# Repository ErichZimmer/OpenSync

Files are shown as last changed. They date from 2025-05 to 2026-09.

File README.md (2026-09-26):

# OpenSync
An open source synchronizer for the velocimetry of fluids using a Raspberry Pi microcontroller.

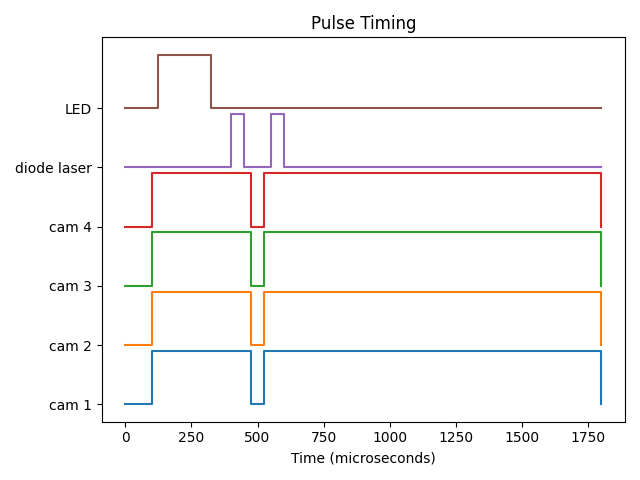
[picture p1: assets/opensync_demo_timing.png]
Example Timing Graph for Diode Laser


## Purpose
OpenSync is a simple and low-cost synchronizer based on microcontroller technology. Due to the intrinsic nature of microcontrollers compared to more advanced devices (e.g., field programmable gate arrays), sub-cycle accuracy and come complex features that are typical of commercial propietary devices are not implemented. However, OpenSync remains sufficiently flexible and provides enough support for most users' needs when performing a PIV experiment. This is because OpenSync is a digital delay/pulse generator capable of having each output channel individually programmed. In adition to an all-microcontroller platform and a custom PCB, OpenSync devices provides a low-cost means to deterministic controll of laboratory equipment.

## Basic Specs
 - **System Frequency**: 250 MHz (4 ns resolution)
 - **Output Channels**: 8
 - **Input Channels**: 2
 - **I/O Channel Voltage**: 3.3V or 5V @ high impedance

For a more detailed specification, please read the [datasheet](documents/datasheet/opensync_datasheet_markdown.md).

## Documentation
Complete instructions to construct and use OpenSync are provided in [imaginary link to notebook-based rtd website]. User's interested in the development process of OpenSync are kindly refered to the [SDLC documentation](documents/SDLC/README.md). There is a lot of information on the development process including some quirks from the pico microcontroller platform.

## Quick Start

### Compilation
OpenSync uses the [RP2350](https://www.raspberrypi.com/products/rp2350/) microcontroller and [Pico SDK](https://www.raspberrypi.com/documentation/microcontrollers/c_sdk.html) as the basis for developing devices that require precise timing with great flexibility. However, there currently isn't an official IDE like the arduino IDE for this microcontroller. Instead, [Microsoft Visual Code](https://code.visualstudio.com/) with the [Pico SDK plugin](https://marketplace.visualstudio.com/items?itemName=raspberry-pi.raspberry-pi-pico) will be used as the IDE to compile the software. Compilation is extremely simple in this context as the IDE and CMake files take care of all the compilation steps. Simply open the root directory of the OpenSync source code with Microsoft Visual Code and click on `>>Compile<<` on the bottom right corner. This will generate the .uf2 file necessary for flashing firmware to the microcontroller.

### Flashing
Flashing firmware to OpenSync is extremely simple. Make sure OpenSync is disconnected from the computer. With the top cover off, press down on the white button on the Pico 2 development board and plug in OpenSync to a computer containing the .uf2 file generated during the compilation process. OpenSync will register itself as a storage device on most computers. Open the folder for OpenSync and drag the .uf2 file into the root directory. OpenSync should then disconnect and reconnect with the computer. During the first bootup, all status LEDs will turn on which indicated that the firmware has been successfully flashed.

### Self Test
Import the Python library `opensync` and type in the following command:
```python
import opensync

# Find all open ports
ports = opensync.device_comm_search()
print(ports)

# Open serial connection with the first opensync device
with opensync.device_comm_managed(ports[0], fast=True) as device:
    # Print manufacturer, model, serial number, and firmware version
    print(opensync.device_system_version(device))

    # Perform a system operation test (raises if something goes wrong)
    opensync.device_system_test(sync_device)

```
If successfull, no errors or warnings should be produced. Please note that all commands to and from opensync are terminated with CRLF. Additionally, all used output terminals should be validated on an osciliscope for peace-of-mind, allthough this is not strictly necessary.

## Acknowledgments
I would like to acknowledge Dr. Ivan Nepomnyashchikh and Professor Alex Liberzon for spearheading development of open source, open hardware equipment for the OpenPIV project (see the original [thread](https://groups.google.com/g/openpiv-users/c/xi7qt28IGEE) that started this project). Additionally, certain inspirations of the OpenSync project are from relatively low-cost hardware produced by [Optolution](https://optolution.com/en/) and [MicroVec Pte Ltd](https://piv.com.sg/). 

## TODO
- [x] Add timing plot utilities
- [x] Add device containerization for customization
- [x] Add the ability to change channel names
- [x] Add the ability to disable output channels (necessary?)
- [x] Add three internal timers that can be mapped to pulse sequences
- [x] Add the ability to count and skip external triggers (usefull for phase-locked stuff like rotor blades)
- [x] Add second external trigger and output port masking
- [x] Update firmware and software to reflect new design
- [ ] Get the damn production PCB produced (keep pushing it off to a later date, umpf)
- [ ] Validate PCB against an osciliscope
- [ ] Add video examples on YouTube

## References
 1. Radim Hošák, & Miroslav Ježek. (2018). Arbitrary digital pulse sequence generator with delay-loop timing. Review of Scientific Instruments, 89(4). https://doi.org/10.1063/1.5019685
 2. Scallon, A. (2017, June 18). Arduino TTL Pulse Generator and Controller. Optogenetics and Neural Engineering Core. https://optogeneticsandneuralengineeringcore.gitlab.io/ONECoreSite/projects/Arduino%20TTL%20Pulse%20Generator%20and%20Controller/
 3. Starkey, P. T., Turnbaugh, C., Miller, P., LeBlanc, K.-J., & Meyer, D. H. (2024). Experimental timing and control using microcontrollers. Review of Scientific Instruments, 95(10). https://doi.org/10.1063/5.0225550
 4. Stasicki, B. and Ehrenfried, K. and Dieterle, L. and Ludwikowski, K. and Raffel, M.  (2001) Advanced syncronization techniques for complex flow field investigations by means of PIV .    4th Intern. Symposium on Particle Image Velocimetry, Göttingen, Germany, September 17-19, 2001.  
    
## Licensing

| Licenses | OSHWA UID |
| --- | --- |
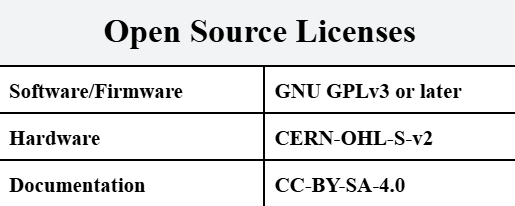
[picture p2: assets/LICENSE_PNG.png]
osls
|  | N/A |

- Software: All firmware and software components are covered by the GNU GPLv3 license.
- Hardware: All hardware is covered by the CERN-OHL-S-v2 license.

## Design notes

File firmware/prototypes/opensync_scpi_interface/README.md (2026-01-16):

# OpenSync SCPI Interface Prototype

This was a quick SCPI interface test using [scpi-parser](https://github.com/j123b567/scpi-parser) by Jan Breuer. This repository is basically a copy of his parser guide from [here](https://www.jaybee.cz/scpi-parser/basic/instrument/) and [USBTMC Pico](https://github.com/jancumps/pico_scpi_usbtmc_labtool) SCPI tool for LabView.

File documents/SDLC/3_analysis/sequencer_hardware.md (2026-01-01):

# On the design and implementation of a Synchronizer Timing Hardware

## Version History
| Date | Version | Change | 
| --- | --- | --- |
| 10/24/2025 | 0.1.0 | Intitial publishment. |
| 12/31/2026 | 0.2.0 | Updated document. |

## Key Words
- GPIO - General Purpose Input/Output
- IC - Internal Circuit
- PCB - Printed Circuit Board

## 1. Introduction
The design and construction of the OpenSync synchronizer will consist of two parts: the PCB and its associated enclosure. The PCB contains all electronics and should ideally require minimal soldering after reception from a PCB assembly vendor. To protect the PCB from the external environment, an enclosure that can be constructed using additive manufacturing technology (e.g., 3D-printing) will also be designed. The combination of easily obtainable PCBs and enclosures is of significant importance as highlighted below.

## 2.1 Enclosure
Electronics, especially specialized laboratory equipment, are often used throughout different environments that require some degree of isolation from. For instance, dusty environments can cause shorts in exposed circuit boards. Enclosures for PCBs are often the most suitable form of isolation for PCBs due to their simplicity. In the case for a multi-channel digital delay/pulse generator, a simple enclosure to protect the housed circuitry is often enough in most scenarios. This allows for the design of an enclosure to fascilitate easy of use while providing protection for internal circuity to be mostly trivial.

Since the main PCB of the synchronizer device is a half Eurocard, standardized enclosures already exist in the European market. The materials of these encolsures range from plastic to aluminium. However, modifying these pre-existing encolusres to the needs of this project may be quite cumbersome. As such, a different approach has been taken through the use of additive manufacturing technology. Additive manufacturing has become significantly more acessibly during recent years. For instance, a vat photopolymerization printer can be aquired from several different Chinese manufactures with manufacturing volumes exceeding 200 mm x 120 mm x 200 mm for less than $300 USD. Furthermore, the precision of these conumer-grade additive manufacturing systems has increased to beyond 20 microns. This is particularly important for the manufacturing of precision nozzles used in helium-filled soap bubble generators.

The use of additive manufacturing to construct enclosures is of particular interest throughout this project due to the ability to manufacturer encolusres with most, if not all, mounts and holes pre-fabricated. This low barrier to fabrication is of particular importance since many potential users of OpenSync synchronizers would be undergraduate students who may lack expertise in manufacturing custom equipment. Moreso, it would be particularly cumbersome to machine 15 holes for SMB jacks and a further 3 for status LEDs, especially for metallic enclosures. To help minimize possible difficulties during hte manufacturing processes, all designs should careffully bear in mind the current liomitations of filamet and resin-based additive manufacturing technologies.

## 2.2 Input/Output Channels
OpenSync is a 16 channel synchronizer that includes a further 3 input channels to help fascilitate advanced fluid flow measurements. The input and output channels are arranged in three rows of five with a gap of 1 cm between the centers of each jack for the input and output channels respectively. Due to the tight proximity of which the input and output jacks are placed, the jacks utilized on this device would be of the type SMB instead of the more common BNC connectors/jacks. SMB connectors do not require a twisting action to create an attachment and instead operate on the basis of friction. This may help reduce the amount of fideling required to connect equipment to the synchronizer. All input and output ports use 50 Ohm resistance at 5V since most laboratory equipment use this level of impedance. 

## 2.3 Microcontroller Circuitry
The main selling point of OpenSync is its low cost of aquisition. This is particularly attributed to the electronics used on the PCB which are based around microcontroller technology. The main sequence processor is the RP2350B (QFN-80 package) microcontroller which runs on 3.3V with rather basic fault tolerance for 5V overvoltages. To minimize the risk of damage to the general purpose input/output (GPIO) pins, a logic level translator is used to profive a buffer between 5V outputs and the 3.3V operatuing voltage of the microcontroller. It is of particular importance that the internal circuit (IC) used for translating 3.3V logic to 5V logic allows for high throughput and low rise/fall times. For this particular case, the SN74LVC8T245 transciever provides a reliable form of logic translation with rise and fall times on the order of nanoseconds on the single digit scale. To provide 5V tolerance to the input channels of the synchronizer, Schmidt triggers are a simple and fast IC that can natively provide 5V tolerance for 3.3V microcontroller oeprating voltages. Beyond ICs that provide 5V tolerances, all other ICs such as the crystal oscilator, 5V to 3V power conversion, and more are nearly identical to that of the RP2350 hardware minimal design example provided by the Raspberry Pi Foudnation.

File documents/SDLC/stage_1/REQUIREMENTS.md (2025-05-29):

# On Requirements for Synchronization of Laboratory Equipment

## Introduction
Synchronization devices play a crucial role in various laboratory experiments, particularly in fields that require precise timing and coordination among multiple components. These devices allow for laboratory equipment to work together in order to accomplish a common task. In the case for fluid dynamics, accurate and precise timing of equipment is particularly important since minor timing discrepancies can lead to non-insignificant errors in data collection and analysis. This has lead to commercial entities providing synchronizing devices with temporal resolutions often less than ten (10) nanoseconds along with advanced timing capabilities that are well suited for even the most complicated laboratory experiments. However, these devices come at the cost of exceedingly high cost-of-ownerships which limits them to institutions and organizations that are well funded. For example, one commercial synchronizer specialized for fluid flow measurements reportedly had a cost-of-ownership of around $9,000 USD (I. Nepomnyi, personal communication, May 18, 2025). Although some commercial entities have since targeted this barrier to entry with lower cost synchronizer models, these models compromize certain features along with cost-of-ownerships that remain a burden to institutions and organizations that are not well-funded.

The high costs of commercial synchronizing devices has lead to a high degree of inginuity in the research community. For instance, the author of this brief paper replaced expensive commercial devices with simple Arduino microcontrollers. While such solutions certainly work, they provide a slew of problems associated with custom firmware implementations. For one, these custom devices often provide limited functionality and sometimes even require reconfiguration of the whole device to change timing parameters. Furthermore, most microcontrollers are not well suited for advanced synchronizing applications due to an intrinsic feature of these devices. This creates a gap in the current research equipment market for an easy to use and advanced low-cost synchronizing device.

Microcontrollers are basically serial devices. This means that parallel execution of code requires the use of multiple cores or peripheral devices. In contrast to microcontrollers, complex programmable logic devices (CPLDs) provide a means for effecient execution of parallel code at the expensive of steeper learning curves due to the utilization of hardware design languages. CPLDs are particularly well suited for synchronization devices and have found several uses in different laboratory settings. Nonetheless, CPLDs are time consuming to program and were not investigated in detail during this brief feasibility study.

## Design Concepts
The RP2040 and RP2350 microcontrollers designed and fabricated by the Raspberry Pi foundation are somewhat unique devices in that they provide a slew of features that make them very attractive for the purposes of controlling laboratory equipment. These microcontrollers provide an efficient means of general input/output (GPIO) manipulation through programmable input/output (PIO) blocks. PIO blocks allow for fast and efficient manipulation of GPIO pins through low-level means. An important feauter of PIO blocks is their ability to run independently from the system clock. This enables for features to be implemented on microcontroller architecture that would otherwise require CPLD or similar devices. The applicability of this microcontroller for the controlling of laboratory equipment was first realized by Starkey et al. (2024) where a pseudoclock and arbitrary pulse generator was implemented with great success. The results from Starkey et al. (2024) provided sufficient evidence to investigate the offerings from the Raspberry Pi foundation for the purpose of engineering an accurate and precise synchronizing device.

The synchronization of laboratory equipment can be broken down into two steps: a synchronization clock source and a pulse generator. A synchronization clock is simply a pulse that occurs at every known timestep to initiate a pulse sequence. Synchronization clocks can be implemented as a mere square wave with a repetition frequency measured in Hertz. The pulse generator is a somewhat more complex as it requires the ability to arbitrarily execute a pulse sequence. These two components allow for the design and implementation of an effective digital pulse generator which could be used to control laboratory equipment. While Starkey et al. (2024) implemented this basic two-component design, their approach requires the utilization of at least two microcontrollers. Instead, two PIO blocks of the RP2040 or RP2350 microcontroller could be utilized for the purposes of combining these two approaches into a singular device. This has the advantage of creating a more compact device that is simpler to construct and program.

## Design Requirements
The effective control of laboratory equipment in both simple and advanced laboratory experiments is no simple feat. The commercial devices often used in these settings mostly provide features and performances that are very good and hard to obtain without in-depth research and design. While the designed synchronizer would most likely not approach performances akin to its commercial counterparts, the synchronizer should still be able to perform most laboratory experiments in a reliable and repeatable manner. This requires the identification of engineering requirements for a device of such cailiber, as seen in Table 1.

Table 1. Engineering Requirements
| Engineering Requirements | Target Value | Justification(s) | 
| --- | --- | --- |
| Power Usage (Watts) | 2.5 W | USB 2.0 can only supply so much voltage (5V @ around 500 mA). |
| Operating Fequency (MHz) | 200 MHz | A 200 MHz oeprating requency allows for a 5ns resolution in timing. |
| Internal Clocks | 4 | 4 internal clocks allows for ample room for advanced hardware synchronization. |
| Output Channels | 16 | 16 output channels provide ample room for hardware synchronization. |
| Input Channels | 2 | 2 input channels provide ample room for hardware synchronization. |
| I/O Channel Resistance (Ohms) | 50 Ohms | 50 Ohms seems to be the standard for device synchronization. |
| Clock Divider | 2 - 2^32-1 | Reduce system clock frequency to tune system to lower frequency conditions. |
| Pulse Width (us) | 1 us to 1 s | Most experiments do not require pulse lengths <1 us or >1 s. |
| Trigger Rate (KHz) | .001 KHz to 100 KHz | Most experiments do not require excessive trigger demands. |
| Internal Jitter (ns) | <10 ns | A 10 ns jitter corresponds to a 1% error or less for timing sequences of >1us resolution. |
| Trigger Jitter (ns) | <10 ns | External trigger jitter should be as low as possible to reduce phase error. 10ns jitter corresponds to <1% error for microsecond scale timing resolution. |
| Communication Protocol | USB | USB on-the-go reduces setup complexity and allows for human-readable serialized commands for ease of use. |
| Housing | 3D-printable | All housing parts should be 3D-printable to enable a wider audience to construct these devices. |

While not an exhaustive list, Table 1 serves as a basic guideline when engineering a synchronizing device. The synchronizer device should be easily constructable with minimal expertise on the user side beyond that of soldering electrical components and 3D printer maintenance and usage. Additionally, all selected electrical components should consume minimal power while being quite performant as USB power delivery is somewhat limited (e.g., ~2.5 W for USB 2.0). This requires carefull consideration of which electrical component should be utilized in order to satisfy most, if not all, of the engineering requirements. Beyond electrical considerations, the firmware of the microcontroller should provide ample means of flexibility to accomodate most use cases. In the case of fluid flow measurements, trigger rates between pulse sequences could occur at different repetition frequencies or require different external trigger configurations (e.g, see Stasicki et al., 2001). This requires for more advanced firmware design that is currently not possible on arduino-like platforms without the utilization of secondary peripheral devices.

## Device Design
The synchronization device, herein coined OpenSync, is a simple and powerfull synchronization device targeting the control of laboritory equipment commonly used in fluid flow diagnostics. OpenSync would provide 16 output channels and two input channels that could be mapped between four internal clocks. The core design of OpenSync revolves around the Raspberry Pi Pico 2 development board which utilizes the RP2350 microcontroller. Typically, the microcontroller chip would be soldered onto a custom printed circuit board (PCB) to exploit its full capabilities. However, this would necessitate the aquisition of a PCB reflow oven due to the usage of quad-flat, no leads (QFN) components which cannot be soldered by hand. This issue has been mostly elliminated by soldering the Pico 2 development board directly onto a custom PCB, thus eliminating technical difficulties that could incur from soldering QFN components. The RP2350 microcontroller has a known issue (errata 9) where a temporary latching behavior could be observed for input GPIO pins. This issue has been nearly circumvented in whole by connecting all active GPIO pins to gound pins via 8K resistors. Thus, the RP2350 microcontroller that is included in the Pico 2 development board has been selected as the best-fit architecture for this project. 

OpenSync would implement a dual architecture pulse logic that exploits the benefits associated with the PIO blocks in the RP2350 microcontroller. Each PIO block contains four state machines that run independent of the main clock. This allows for efficient manipulation of GPIO pins through programs written in a low-level language. For instance, state machines can run programs that utilize a subset of the assembly language coined PIO assembly (pioasm) that contains only seven instructions. Each instruction usually takes a single clock cycle to execute unless the state machine is stalled for one reason or another. This allows for very efficient programms to be written in pioasm that require minimal intervention with the main microcontroller processor. One issue with this configuration is that two PIO blocks cannot communicate between each other. As such, alternative means for syncronizing state machines between PIO blocks would be necessary and will be discussed later.

The dual architecture pulse logic would be implemented in two ways: one PIO block specializing in synchronizing clock sources and another PIO block focused on arbitrary pulse generation. The first PIO block, focused primarily on generating square waves for synchronizing pulse sequences, would utilize four state machines with each one synchronized within a single clock cycle of eachother. A basic pioasm program would be loaded into the memory of each state machine and executed with user-defined pulsing parameters. The pioasm program would take five inputs: external trigger pin, external trigger delay, external trigger skip, pulse repetition freqency, and pulse quantity. The control of the external trigger is defined by the first instruction in the pulse repetition frequency array which sets a flag in one of the scratch registers of the pioasm program. The amount of external triggers to skipped before triggering is controlled by the first instruction of the pulse quantity array and is stored in a second scratch register for later use. Each state machine operates its own instance of the pioasm program which enables for up to four independent clock signals to be sent simultaneously. The second PIO block focuses on an arbitrary pulse generator capable of producing up to 16 pulses (32 instructions in total) and operates in a similar fashion to the arbitrary pulse generator in Starkey et al. (2024). Similar to the pioasm program in PIO block 1, the four instances of the arbitary pulse generator pioasm program are mapped to all 16 output channels and are capable of operating asynchronously. However, mapping the state machine from PIO block 1 and PIO block 2 is not possible via firmware due to these blocks oeprating as independent systems. As such, an unconventional approach could be used to circumvent this issue.

As mentioned above, each PIO block operates mostly independent of each other. This creates a challenge when two PIO blocks are required to communicate between the two to accomplish a certain task. There are several methods to solve this challenge, however the one chosen for this project is somewhat uncommon. An interesting feature of the RP2350 microcontroller is the ability for any input GPIO pin to passivly "spy" on the state of another GPIO pin. This GPIO pin can be either configured as an output or input pin as the pin direction does not matter much in this context. This feature can be exploited by selecting four unused GPIO pins as an output pin that is mapped to one of each synchronization clocks in PIO block 1. Now, each pioasm program on PIO block 2 can passively spy on their respective GPIO trigger pin in order to determine when to execute the pulse sequence. Naturally, this method of triggering a pioasm program through stalling the state machine until a start signal is recieved would be slower on comparison to software interupts. This is because the internal trigger signal may need up to four clock cycles to be detected due to the implementation of GPIO inputs and outputs in the RP2350 architecture. This has an additional side-effect of which the internal trigger signal must be at least four clock cycles long in order to properly resolve the trigger. Since the internal trigger would theoretically would not be repeated for frequencies >1 MHz at a peak system clock frequency of 200 MHz, a trigger signal of 10 cycles was deemed sufficient for the purpose of synchronizing each channel of PIO block 2. Using this methodology, two PIO blocks can effectively communicate with each other in order to perform advanced pulse sequencing required in certain fluid flow diagnostic experiments.

## References

 1. RP2350 Datasheet, A Microcontroller by Raspberry Pi. (2023). Raspberry Pi Ltd. https://datasheets.raspberrypi.com/rp2350/rp2350-datasheet.pdf
 2. Starkey, P. T., Turnbaugh, C., Miller, P., LeBlanc, K.-J., & Meyer, D. H. (2024). Experimental timing and control using microcontrollers. Review of Scientific Instruments, 95(10). https://doi.org/10.1063/5.0225550
 3. Stasicki, B. and Ehrenfried, K. and Dieterle, L. and Ludwikowski, K. and Raffel, M.  (2001) Advanced syncronization techniques for complex flow field investigations by means of PIV .    4th Intern. Symposium on Particle Image Velocimetry, Göttingen, Germany, September 17-19, 2001.

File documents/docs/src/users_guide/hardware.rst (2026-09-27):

Hardware Guide
==============

.. note::

   **Placeholder:** the hardware construction guide has not been written yet.

This guide will cover the physical construction of an OpenSync device:

* **Electronics:** circuit boards, components, connectors, and wiring.
* **Enclosure:** housing design and mounting the electronics.
* **Machining:** enclosure openings, panel preparation, and mechanical parts.
* **Construction:** assembly sequence and checks on the completed device.

Detailed instructions, drawings, and assembly photographs will be added here.
For an assembled device, continue to the :doc:`firmware` or :doc:`software`.

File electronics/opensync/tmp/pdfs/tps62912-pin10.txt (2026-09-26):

                                                                                                                             TPS62912, TPS62913
                                                                                              SLVSFP4B – AUGUST 2020 – REVISED MARCH 2021

     TPS6291x 3-V to 17-V, 2-A/3-A Low Noise and Low Ripple Buck Converter with
                     Integrated Ferrite Bead Filter Compensation

1 Features                                                             3 Description
•   Low output 1/f noise < 20 µVRMS                                    The TPS6291x devices are a family of high-efficiency,
    (100 Hz to 100 kHz)                                                low noise and low ripple current mode synchronous
•   Low output voltage ripple < 10 µVRMS after ferrite                 buck converters. The devices are ideal for noise
    bead                                                               sensitive applications that would normally use an LDO
•   High PSRR of > 65 dB (up to 100 kHz)                               for post regulation such as high-speed ADCs, clock
•   2.2-MHz or 1-MHz fixed frequency peak current                      and jitter cleaner, serializer, de-serializer, and radar
    mode control                                                       applications.
•   Synchronizable with external clock (optional)                      The devices operate at a fixed switching frequency of
•   Integrated loop compensation supports ferrite                      2.2 MHz or 1 MHz, and can be synchronized to an
    bead for second stage L-C filter with 30-dB                        external clock.
    attenuation (optional)                                             To further reduce the output voltage ripple, the device
•   Spread spectrum modulation (optional)                              integrates loop compensation to operate with an
•   3.0-V to 17-V input voltage range                                  optional second-stage ferrite bead L-C filter. This
•   0.8-V to 5.5-V output voltage range                                allows an output voltage ripple below 10 µVRMS.
•   57-mΩ/20-mΩ RDSon                                                  Low-frequency noise levels, similar to a low-noise
•   Output voltage accuracy of ±1%                                     LDO, are achieved by filtering the internal voltage
•   Precise enable input allows                                        reference with a capacitor connected to the NR/SS
    – User-defined undervoltage lockout                                pin.
    – Exact sequencing                                                 The optional spread spectrum modulation scheme
•   Adjustable soft start                                              spreads the DC/DC switching frequency over a wider
•   Power-good output                                                  span, which lowers the mixing spurs.
•   Output discharge (optional)
                                                                                               Device Information
•   –40°C to 150°C junction temperature range
                                                                         DEVICE         OUTPUT                         (1)
•   2.0-mm × 2.0-mm QFN with 0.5-mm pitch                                                              PACKAGE                  BODY SIZE (NOM)
                                                                          NAME         CURRENT
•   Create a custom design using the TPS6291x with                     TPS62912             2A
    the WEBENCH® Power Designer                                                                         QFN (10)                 2.0 mm × 2.0 mm
                                                                       TPS62913             3A
2 Applications                                                         (1)    For all available packages, see the orderable addendum at
•   Telecom infrastructure                                                    the end of the data sheet.
•   Test and measurement
•   Aerospace and defense (radar/avionics)
•   Medical
                                                                                                                                      Ferrite
                                                                                                       2.2µH                          Bead
                                                             Vin                     VIN         SW                                                      Vo
                                                             12V                                                                                      3.3V/3A
                                                              2x10µF                 EN/SYNC     VO
                                                                                                                             3x22µF
                                                                                     S-CONF      FB
                                                                                                                                            15.4k
                                                                             2.2nF                                                                  2x22µF
                                                                                     PSNS      NR/SS
                                                                                                               470nF                        4.87k
                                                                                     PGND        PG

                                                                                              Typical Application
            Output Noise Versus Frequency

     An IMPORTANT NOTICE at the end of this data sheet addresses availability, warranty, changes, use in safety-critical applications,
     intellectual property matters and other important disclaimers. PRODUCTION DATA.

TPS62912, TPS62913
SLVSFP4B – AUGUST 2020 – REVISED MARCH 2021                                                                                                                      www.ti.com

                                                                        Table of Contents
1 Features............................................................................1     7.4 Device Functional Modes..........................................21
2 Applications..................................................................... 1     8 Application and Implementation.................................. 22
3 Description.......................................................................1       8.1 Application Information............................................. 22
4 Revision History.............................................................. 2          8.2 Typical Applications.................................................. 22
5 Pin Configuration and Functions...................................3                     9 Power Supply Recommendations................................30
6 Specifications.................................................................. 4      10 Layout...........................................................................30
  6.1 Absolute Maximum Ratings ....................................... 4                    10.1 Layout Guidelines................................................... 30
  6.2 ESD Ratings .............................................................. 4          10.2 Layout Example...................................................... 31
  6.3 Recommended Operating Conditions ........................4                          11 Device and Documentation Support..........................33
  6.4 Thermal Information ...................................................5              11.1 Device Support........................................................33
  6.5 Electrical Characteristics ............................................5              11.2 Receiving Notification of Documentation Updates.. 33
  6.6 Typical Characteristics................................................ 7             11.3 Support Resources................................................. 33
7 Detailed Description......................................................17              11.5 Electrostatic Discharge Caution.............................. 33
  7.1 Overview................................................................... 17        11.6 Glossary.................................................................. 33
  7.2 Functional Block Diagram......................................... 17                12 Mechanical, Packaging, and Orderable
  7.3 Feature Description...................................................18              Information.................................................................... 34

4 Revision History
Changes from Revision A (September 2020) to Revision B (March 2021)                                                        Page
• Changed device status from Advance Information to Production Data ............................................................. 1

2       Submit Document Feedback                                                                                           Copyright © 2021 Texas Instruments Incorporated

                                                              Product Folder Links: TPS62912 TPS62913

                                                                                                                                      TPS62912, TPS62913
www.ti.com                                                                                                      SLVSFP4B – AUGUST 2020 – REVISED MARCH 2021

5 Pin Configuration and Functions
                                                           PGND 4                            3 VO
                                                               PG 5                          2 SW
                                                              VIN 6                          1 EN/SYNC

                                                                      7     8       9 10

                                                                            NR/SS
                                                                                    FB
                                                                                         S-CONF
                                                                     PSNS
                                          Figure 5-1. 10-Pin QFN RPU Package (Top View)

                                                              Table 5-1. Pin Functions
           PIN
                           I/O                                                                    DESCRIPTION
    NO.     NAME
                                 Enable/Disable pin including threshold-comparator. Connect to logic low to disable the device. Pull high to enable the device.
     1      EN/SYNC         I    This pin has an internal pulldown resistor of typically 500 kΩ when the device is disabled. Apply a clock to this pin to
                                 synchronize the device.
     2      SW             I/O   Switch pin of the power stage
     3      VO              I    Output voltage sense pin. This pin needs to be connected directly after the first inductor.
     4      PGND                 Power ground connection
                                 Open-drain power-good output. This pin is pulled to GND when VOUT is below the power-good threshold. It requires a pullup
     5      PG              O
                                 resistor to output a logic high. It can be left open or tied to GND if not used.
     6      VIN             I    Power supply input voltage pin
     7      PSNS            I    Power sense ground. Connect directly to the ground plane.
     8      NR/SS           O    A capacitor connected to this pin sets the soft-start time and low frequency noise level of the device.
     9      FB              I    Feedback pin of the device
     10     S-CONF          O    Smart Configuration pin. This pin configures the operation modes of the device. See Table 7-1.

Copyright © 2021 Texas Instruments Incorporated                                                                                Submit Document Feedback           3
                                                      Product Folder Links: TPS62912 TPS62913

TPS62912, TPS62913
SLVSFP4B – AUGUST 2020 – REVISED MARCH 2021                                                                                               www.ti.com

6 Specifications
6.1 Absolute Maximum Ratings
over operating junction temperature range (unless otherwise noted)(1)
                                                                                                        MIN                MAX            UNIT
                         VIN, EN/SYNC, PG, S-CONF                                                      – 0.3                  18           V
                         SW (DC)                                                                       – 0.3          VIN + 0.3            V
    Voltage(2)           SW (AC, less than 10ns)(3)                                                    – 2.5                  21           V
                         VO, FB, NR/SS                                                                 – 0.3                   6           V
                         PSNS                                                                          – 0.3                  0.3          V
    Sink Current         PG                                                                                                   10          mA
    TJ                   Junction temperature                                                           –40                150             °C
    Tstg                 Storage temperature                                                            –65                150             °C

(1)          Stresses beyond those listed under Absolute Maximum Rating may cause permanent damage to the device. These are stress
             ratings only, which do not imply functional operation of the device at these or any other conditions beyond those indicated
             under Recommended Operating Condition. Exposure to absolute-maximum-rated conditions for extended periods may affect device
             reliability.
(2)          All voltage values are with respect to the network ground terminal
(3)          While switching

6.2 ESD Ratings
                                                                                                                      VALUE                UNIT
                                                       Human body model (HBM), per ANSI/ESDA/JEDEC JS-001,
                                                                                                                      ±2000
                                                       all pins(1)
    V(ESD)             Electrostatic discharge                                                                                              V
                                                       Charged device model (CDM), per JEDEC specification
                                                                                                                       ±500
                                                       JESD22-C101, all pins(2)

(1)          JEDEC document JEP155 states that 500-V HBM allows safe manufacturing with a standard ESD control process.
(2)          JEDEC document JEP157 states that 250-V CDM allows safe manufacturing with a standard ESD control process.

6.3 Recommended Operating Conditions
over operating junction temperature range (unless otherwise noted)
                                                                                                     MIN          NOM           MAX         UNIT
    VIN             Input voltage                                                                     3.0                            17         V
    VOUT            Output voltage                                                                    0.8                           5.5         V
    CIN             Effective input capacitance                                                         5            10                        µF
    L1              Effective output inductance                                                     -30%       2.2 / 4.7            20%        µH
    COUT            Effective output capacitance                                                       40            47              80        µF
    Lf              Effective filter inductance                                                         0            10              50        nH
    Cf              Effective filter capacitance                                                       20            40             160        µF
    COUT + Cf       Effective total output capacitance, including first and second L-C filter          40                           200        µF
    IOUT            Output current for TPS62913                                                         0                             3         A
    IOUT            Output current for TPS62912                                                         0                             2         A
    TJ (1)          Junction temperature                                                             –40                            150        °C

(1)          Operating lifetime is derated at junction temperatures above 125°C.

4            Submit Document Feedback                                                                  Copyright © 2021 Texas Instruments Incorporated

                                                         Product Folder Links: TPS62912 TPS62913

                                                                                                                                TPS62912, TPS62913
www.ti.com                                                                                           SLVSFP4B – AUGUST 2020 – REVISED MARCH 2021

6.4 Thermal Information
                                                                                                     TPS6291x
                           THERMAL METRIC(1)                                                     RPU 10-pin QFN                              UNIT
                                                                                 JEDEC 51-7 PCB              TPS6291xEVM-077
 RθJA             Junction-to-ambient thermal resistance                                87.7                          56.6                   °C/W
 RθJC(top)        Junction-to-case (top) thermal resistance                             61.9                          n/a (2)                °C/W
 RθJB             Junction-to-board thermal resistance                                  22.2                          n/a (2)                °C/W
 ΨJT              Junction-to-top characterization parameter                             1.9                           1.3                   °C/W
 YJB              Junction-to-board characterization parameter                          22.2                          22.7                   °C/W

(1)       For more information about traditional and new thermal metrics, see the Semiconductor and IC Package Thermal Metrics application
          report.
(2)       Not applicable to an EVM

6.5 Electrical Characteristics
Over recommended input voltage range, TJ= -40℃ to 150℃. Typical values are at Vin=12V andTJ=25℃ (unless otherwise
noted)
                       PARAMETER                                          TEST CONDITIONS                     MIN          TYP       MAX      UNIT
 SUPPLY
                                                            EN = High, no load, device switching, fsw
 IQ            Quiescent current                                                                                                 5            mA
                                                            = 1 MHz
 ISD           Shutdown current                             EN = GND, TJ = -40°C to 125°C                                    0.3       70      µA
 VUVLO         Undervoltage lockout                         VIN rising, TJ = -40°C to 125°C                   2.85         2.92        3.0     V
 VUVLO         Undervoltage lockout                         VIN rising                                                                3.04     V
 VHYS          Undervoltage lockout hysteresis                                                                               200              mV
               Thermal shutdown threshold                   TJ rising                                                        170               °C
 TJSD
               Thermal shutdown hysteresis                  TJ falling                                                          20             °C
 CONTROL and INTERFACE
               High-level input-threshold voltage at EN/
 VH_EN                                                                                                        0.97         1.01       1.04     V
               SYNC
               Low-level input-threshold voltage at EN/
 VL_EN                                                                                                        0.87           0.9      0.93     V
               SYNC
               High-level input-threshold clock signal on
 VH_SYNC                                                    EN/SYNC = clock                                     1.1                            V
               EN/SYNC
               Low-level input-threshold clock signal on
 VL_SYNC                                                    EN/SYNC = clock                                                            0.4     V
               EN/SYNC
                                                            EN/SYNC = GND or VIN, –40℃ ≤ TJ ≤
 IEN,LKG       Input leakage current into EN/SYNC                                                                                5    160      nA
                                                            125℃
 RPD           Pulldown resistor on EN/SYNC                 EN/SYNC = Low                                       330          500               kΩ
                                                            Time from EN/SYNC high to device starts
 tdelay        Enable delay time                                                                                                 1             ms
                                                            switching, RS-CONF = 80.6 kΩ
 INR/SS        NR/SS source current                                                                           67.5              75    82.5     µA
                                                            RS-CONF tolerance for all settings
 RS-CONF       S-CONF resistor step range accuracy                                                            –4%                     +4%
                                                            according to S-CONF Table
 VPG           Power good threshold                         VFB rising, referenced to VFB nominal             93%          95%        98%
 VPG           Power good threshold                         VFB falling, referenced to VFB nominal            88%          90%        93%
 VPG,OL        Low-level output voltage at PG pin           ISINK = 1 mA                                                               0.4     V
 IPG,LKG       Input leakage current into PG pin            VPG = 5 V; –40℃ ≤ TJ ≤ 125℃                                          5    500      nA
 tPG,DLY       Power good delay time                        VFB falling                                                          8             µs
 OUTPUT

Copyright © 2021 Texas Instruments Incorporated                                                                   Submit Document Feedback           5
                                                    Product Folder Links: TPS62912 TPS62913

TPS62912, TPS62913
SLVSFP4B – AUGUST 2020 – REVISED MARCH 2021                                                                                       www.ti.com

Over recommended input voltage range, TJ= -40℃ to 150℃. Typical values are at Vin=12V andTJ=25℃ (unless otherwise
noted)
                          PARAMETER                               TEST CONDITIONS                      MIN        TYP        MAX      UNIT
    ton          Minimum on-time                      VIN ≥ 5 V, Iout = 1 A                                         35          70      ns
    toff         Minimum off-time                     VIN ≥ 5 V, Iout = 1 A                                         50          60      ns
    VFB          Feedback regulation accuracy         –40℃ ≤TJ ≤ 150℃                                0.792         0.8      0.812       V
    VFB          Feedback regulation accuracy         –40℃ ≤ TJ ≤ 125℃                               0.792         0.8      0.808       V
    IFB,LKG      Input leakage current into FB        VFB = 0.8 V, –40℃ ≤ TJ ≤ 125℃                                  1          70     nA
    IVO,LKG      Input leakage current into VO        VVO = 1.2 V, –40℃ ≤ TJ ≤ 125℃                               0.01          30     µA
                                                      VIN = 12 V, 1.2 VOUT, 1 A, CNR/SS = 470
    PSRR         Power supply rejection ratio         nF, fsw = 1 MHz, CFF = open, L1 = 2.2 µH,                     65                 dB
                                                      COUT = 3 × 22 µF, f ≤ 100 kHz
                                                      VIN = 5 V, 1.2 VOUT, 1 A, CNR/SS = 470 nF,
    PSRR         Power supply rejection ratio         fsw = 2.2 MHz, CFF = open, L1 = 2.2 µH,                       70                 dB
                                                      COUT = 3 × 22 µF, f ≤ 100 kHz
                                                      VIN = 12 V, BW = 100 Hz to 100 kHz, CNR/
                                                      SS = 470 nF, fSW = 1 MHz, VOUT = 1.2 V,
    VNRMS        Output voltage RMS noise                                                                         24.4               µVRMS
                                                      CFF = open, L1 = 2.2 µH, COUT = 3 × 22
                                                      µF
                                                      VIN = 5 V, BW = 100 Hz to 100 kHz, CNR/
                                                      SS = 470 nF, fSW = 2.2 Hz, VOUT = 1.2 V,
    VNRMS        Output voltage RMS noise                                                                         13.5               µVRMS
                                                      CFF = open, L1 = 2.2 µH, COUT = 3 × 22
                                                      µF
                                                      VIN = 12 V, fSW = 1 MHz, VOUT = 1.2 V, L1
    Vopp         Output ripple voltage at fSW         = 4.7 µH, COUT = 3 × 22 µF, Lf = 10 nH,                        9               µVRMS
                                                      Cf = 2 × 22 µF
                                                      VIN = 5 V, fSW = 2.2 MHz, VOUT = 1.2 V, L1
    Vopp         Output ripple voltage at fSW         = 2.2 µH, COUT = 3 × 22 µF, Lf = 10 nH,                    < 2.2               µVRMS
                                                      Cf = 2 × 22 μF
                                                      EN/SYNC = GND, VOUT = 1.2 V, VIN ≥ 5
    RDIS         Output discharge resistance                                                                          7                 Ω
                                                      V. See Typical Char for plot.
                                                      EN/SYNC = GND, VOUT = 5 V, VIN ≥ 5 V.
    RDIS         Output discharge resistance                                                                        32                  Ω
                                                      See Typical Char for plot.
    fSW          Switching frequency                  2.2-MHz setting                                 1.98         2.2        2.42    MHz
    fSW          Synchronization range                2.2-MHz setting                                   1.9        2.2        2.42    MHz
    fSW          Switching frequency                  1-MHz setting                                     0.9          1        1.18    MHz
    fSW          Synchronization range                1-MHz setting                                   0.86           1         1.2    MHz
    DSYNC        Synchronization duty cycle                                                           45%                     55%
                                                      Phase delay from EN/SYNC rising edge
    tsync_elay   Synchronization phase delay                                                                        90                  ns
                                                      to SW rising edge
    ISWpeak      Peak switch current limit            TPS62912                                          2.9        3.5         4.0      A
    ISWpeak      Peak switch current limit            TPS62913                                          3.7        4.3         5.1      A
    ISWvalley    Valley switch current limit          TPS62912                                                     3.4                  A
    ISWvalley    Valley switch current limit          TPS62913                                                     4.2                  A
    Inegvalley Negative valley current limit                                                                     –1.39      –0.96       A
                 High-side FET on-resistance          VIN ≥ 5 V                                                     57          95     mΩ
    RDS(ON)
                 Low-side FET on-resistance           VIN ≥ 5 V                                                     20          39     mΩ

6          Submit Document Feedback                                                                Copyright © 2021 Texas Instruments Incorporated

                                                 Product Folder Links: TPS62912 TPS62913

                                                                                                                  TPS62912, TPS62913
www.ti.com                                                                                   SLVSFP4B – AUGUST 2020 – REVISED MARCH 2021

6.6 Typical Characteristics
VIN = 12 V, VOUT = 1.2 V, TA = 25°C, BOM = Table 8-1, (unless otherwise noted)

                                                                                                BW = 10 kHz
   12 V to 1.2 V, 1 A       2.2 μH, 1 MHz         First L-C Only
                                                                        12 V to 1.2 V, 1 A     2.2 μH, 1 MHz       First L-C Only
           Figure 6-1. VOUT Ripple After the First L-C Filter
                                                                             Figure 6-2. VOUT Ripple FFT After the First L-C Filter

                                                                                               BW = 10 kHz
   12 V to 1.2 V, 1 A      2.2 μH, 1 MHz      First and second L-C
                                                                        12 V to 1.2 V, 1 A     2.2 μH, 1 MHz   First and second L-C
         Figure 6-3. VOUT Ripple After the Second L-C Filter
                                                                           Figure 6-4. VOUT Ripple FFT After the Second L-C Filter

   12 V to 1.2 V, 1 A       2.2 μH, 1 MHz         First L-C Only        12 V to 1.2 V, 1 A    2.2 μH, 1 MHz    First and second L-C

              With Random Spread Spectrum Enabled                                With Random Spread Spectrum Enabled

           Figure 6-5. VOUT Ripple After the First L-C Filter                Figure 6-6. VOUT Ripple After the Second L-C Filter

Copyright © 2021 Texas Instruments Incorporated                                                           Submit Document Feedback         7
                                                   Product Folder Links: TPS62912 TPS62913

TPS62912, TPS62913
SLVSFP4B – AUGUST 2020 – REVISED MARCH 2021                                                                                    www.ti.com

6.6 Typical Characteristics (continued)

    12 V to 1.8 V, 1 A    2.2 μH, 1 MHz        First L-C Only
                                                                                             BW = 10 kHz

                                                                      12 V to 1.8 V, 1 A    2.2 μH, 1 MHz          First L-C Only
           Figure 6-7. VOUT Ripple After the First L-C Filter
                                                                           Figure 6-8. VOUT Ripple FFT After the First L-C Filter

    12 V to 1.8 V, 1 A   2.2 μH, 1 MHz     First and second L-C
                                                                                            BW = 10 kHz

                                                                      12 V to 1.8 V, 1 A   2.2 μH, 1 MHz      First and second L-C
         Figure 6-9. VOUT Ripple After the Second L-C Filter
                                                                         Figure 6-10. VOUT Ripple FFT After the Second L-C Filter

    12 V to 3.3 V, 1 A   2.2 μH, 2.2 MHz       First L-C Only
                                                                                             BW = 10 kHz

                                                                      12 V to 3.3 V, 1 A   2.2 μH, 2.2 MHz         First L-C Only
          Figure 6-11. VOUT Ripple After the First L-C Filter
                                                                          Figure 6-12. VOUT Ripple FFT After the First L-C Filter

8      Submit Document Feedback                                                                 Copyright © 2021 Texas Instruments Incorporated

                                                 Product Folder Links: TPS62912 TPS62913

                                                                                                                  TPS62912, TPS62913
www.ti.com                                                                                   SLVSFP4B – AUGUST 2020 – REVISED MARCH 2021

6.6 Typical Characteristics (continued)

   12 V to 3.3 V, 1 A     2.2 μH, 2.2 MHz     First and second L-C
                                                                                               BW = 10 kHz

                                                                        12 V to 3.3 V, 1 A    2.2 μH, 2.2 MHz   First and second L-C
         Figure 6-13. VOUT Ripple After the Second L-C Filter
                                                                           Figure 6-14. VOUT Ripple FFT After the Second L-C Filter

    5 V to 1.2 V, 1 A      2.2 μH, 2.2 MHz        First L-C Only
                                                                                                BW = 10 kHz

                                                                         5 V to 1.2 V, 1 A    2.2 μH, 2.2 MHz       First L-C Only
          Figure 6-15. VOUT Ripple After the First L-C Filter
                                                                            Figure 6-16. VOUT Ripple FFT After the First L-C Filter

    5 V to 1.2 V, 1 A     2.2 μH, 2.2 MHz     First and second L-C
                                                                                               BW = 10 kHz

                                                                         5 V to 1.2 V, 1 A    2.2 μH, 2.2 MHz   First and second L-C
         Figure 6-17. VOUT Ripple after the Second L-C Filter
                                                                           Figure 6-18. VOUT Ripple FFT After the Second L-C Filter

Copyright © 2021 Texas Instruments Incorporated                                                           Submit Document Feedback         9
                                                   Product Folder Links: TPS62912 TPS62913

TPS62912, TPS62913
SLVSFP4B – AUGUST 2020 – REVISED MARCH 2021                                                                                   www.ti.com

6.6 Typical Characteristics (continued)

     5 V to 1.8 V, 1 A    2.2 μH, 2.2 MHz       First L-C Only
                                                                                             BW = 10 kHz

                                                                       5 V to 1.8 V, 1 A   2.2 μH, 2.2 MHz        First L-C Only
           Figure 6-19. VOUT Ripple After the First L-C Filter
                                                                          Figure 6-20. VOUT Ripple FFT After the First L-C Filter

     5 V to 1.8 V, 1 A   2.2 μH, 2.2 MHz    First and second L-C
                                                                                            BW = 10 kHz

                                                                       5 V to 1.8 V, 1 A   2.2 μH, 2.2 MHz   First and second L-C
         Figure 6-21. VOUT Ripple After the Second L-C Filter
                                                                         Figure 6-22. VOUT Ripple FFT After the Second L-C Filter

     5 V to 3.3 V, 1 A    2.2 μH, 2.2 MHz       First L-C Only
                                                                                             BW = 10 kHz

                                                                       5 V to 3.3 V, 1 A   2.2 μH, 2.2 MHz        First L-C Only
           Figure 6-23. VOUT Ripple After the First L-C Filter
                                                                          Figure 6-24. VOUT Ripple FFT After the First L-C Filter

10      Submit Document Feedback                                                               Copyright © 2021 Texas Instruments Incorporated

                                                 Product Folder Links: TPS62912 TPS62913

                                                                                                                      TPS62912, TPS62913
www.ti.com                                                                                   SLVSFP4B – AUGUST 2020 – REVISED MARCH 2021

6.6 Typical Characteristics (continued)

    5 V to 3.3 V, 1 A     2.2 μH, 2.2 MHz     First and second L-C
                                                                                                BW = 10 kHz

                                                                         5 V to 3.3 V, 1 A    2.2 μH, 2.2 MHz      First and second L-C
         Figure 6-25. VOUT Ripple After the Second L-C Filter
                                                                           Figure 6-26. VOUT Ripple FFT After the Second L-C Filter

    6 V to 1.2 V, 1 A       2.2 μH, 1 MHz          BW = 50 Hz           12 V to 1.2 V, 2 A      2.2 μH, 1 MHz           BW = 10 kHz

                S-CONF = OFF, Triangular, Random                                     S-CONF = OFF, Triangular, Random

            Figure 6-27. Spread Spectrum FFT - 50-Hz BW                         Figure 6-28. Spread Spectrum FFT - 10-kH BW

       12 V to 1.2 V         2.2 μH, 1 MHz         First L-C Only          12 V to 1.2 V       2.2 μH, 1 MHz       After ferrite bead filter

     NR/SS = Open, 100 nF, 470 nF, 2.2 μF, BW = 100 Hz to 100 kHz         NR/SS = Open, 100 nF, 470 nF, 2.2 μF, BW = 100 Hz to 100 kHz

           Figure 6-29. Output Noise Density vs Frequency                      Figure 6-30. Output Noise Density vs Frequency

Copyright © 2021 Texas Instruments Incorporated                                                                Submit Document Feedback        11
                                                   Product Folder Links: TPS62912 TPS62913

TPS62912, TPS62913
SLVSFP4B – AUGUST 2020 – REVISED MARCH 2021                                                                                              www.ti.com

6.6 Typical Characteristics (continued)

        12 V to 1.2 V         2.2 μH, 1 MHz          First L-C Only         12 V to 1.2 V        2.2 μH, 1 MHz       After ferrite bead filter

     NR/SS = 470 nF, CFF = Open, 100 nF, 1 μF, BW = 100 Hz to 100 kHz     NR/SS = 470 nF, CFF = Open, 100 nF, 1 μF, BW = 100 Hz to 100 kHz

            Figure 6-31. Output Noise Density vs Frequency                       Figure 6-32. Output Noise Density vs Frequency

        12 V to 1.8 V         2.2 μH, 1 MHz          First L-C Only          12 V to 1.8 V       2.2 μH, 1 MHz       After ferrite bead filter

       NR/SS = Open, 100 nF, 470 nF, 2.2 μF, BW = 100 Hz to 100 kHz         NR/SS = Open, 100 nF, 470 nF, 2.2 μF, BW = 100 Hz to 100 kHz

            Figure 6-33. Output Noise Density vs Frequency                       Figure 6-34. Output Noise Density vs Frequency

        12 V to 1.8 V         2.2 μH, 1 MHz          First L-C Only         12 V to 1.8 V        2.2 μH, 1 MHz      After ferrite bead filter

     NR/SS = 470 nF, CFF = Open, 100 nF, 1 μF, BW = 100 Hz to 100 kHz     NR/SS = 470 nF, CFF = Open, 100 nF, 1 μF, BW = 100 Hz to 100 kHz

            Figure 6-35. Output Noise Density vs Frequency                       Figure 6-36. Output Noise Density vs Frequency

12       Submit Document Feedback                                                                     Copyright © 2021 Texas Instruments Incorporated

                                                     Product Folder Links: TPS62912 TPS62913

                                                                                                                     TPS62912, TPS62913
www.ti.com                                                                                   SLVSFP4B – AUGUST 2020 – REVISED MARCH 2021

6.6 Typical Characteristics (continued)

                                                                           12 V to 3.3 V        2.2 μH, 2.2 MHz     After ferrite bead filter
       12 V to 3.3 V        2.2 μH, 2.2 MHz        First L-C Only
                                                                          NR/SS = Open, 100 nF, 470 nF, 2.2 μF, BW = 100 Hz to 100 kHz
     NR/SS = Open, 100 nF, 470 nF, 2.2 μF, BW = 100 Hz to 100 kHz

                                                                               Figure 6-38. Output Noise Density vs Frequency
           Figure 6-37. Output Noise Density vs Frequency

       12 V to 3.3 V        2.2 μH, 2.2 MHz        First L-C Only          12 V to 3.3 V        2.2 μH, 2.2 MHz     After ferrite bead filter

   NR/SS = 470 nF, CFF = Open, 100 nF, 1 μF, BW = 100 Hz to 100 kHz     NR/SS = 470 nF, CFF = Open, 100 nF, 1 μF, BW = 100 Hz to 100 kHz

           Figure 6-39. Output Noise Density vs Frequency                      Figure 6-40. Output Noise Density vs Frequency

       5 V to 1.2 V         2.2 μH, 2.2 MHz        First L-C Only           5 V to 1.2 V        2.2 μH, 2.2 MHz     After ferrite bead filter

     NR/SS = Open, 100 nF, 470 nF, 2.2 μF, BW = 100 Hz to 100 kHz         NR/SS = Open, 100 nF, 470 nF, 2.2 μF, BW = 100 Hz to 100 kHz

           Figure 6-41. Output Noise Density vs Frequency                      Figure 6-42. Output Noise Density vs Frequency

Copyright © 2021 Texas Instruments Incorporated                                                             Submit Document Feedback            13
                                                   Product Folder Links: TPS62912 TPS62913

TPS62912, TPS62913
SLVSFP4B – AUGUST 2020 – REVISED MARCH 2021                                                                                                 www.ti.com

6.6 Typical Characteristics (continued)

       5 V to 3.3 V           2.2 μH, 2.2 MHz       First L-C Only               5 V to 3.3 V         2.2 μH, 2.2 MHz     After ferrite bead filter

     NR/SS = Open, 100 nF, 470 nF, 2.2 μF, BW = 100 Hz to 100 kHz              NR/SS = Open, 100 nF, 470 nF, 2.2 μF, BW = 100 Hz to 100 kHz

          Figure 6-43. Output Noise Density vs Frequency                            Figure 6-44. Output Noise Density vs Frequency

     12 V to 1.2 V            2.2 μH, 1 MHz         1 A, 2 A, 3 A              12 V to 1.2 V          2.2 μH, 1 MHz           1 A, 2 A, 3 A

                      First L-C Only, No Ferrite Bead                                             After Ferrite Bead Filter

                      Figure 6-45. PSRR vs Frequency                                            Figure 6-46. PSRR vs Frequency

     12 V to 1.8 V            2.2 μH, 1 MHz         1 A, 2 A, 3 A              12 V to 1.8 V          2.2 μH, 1 MHz           1 A, 2 A, 3 A

                      First L-C Only, No Ferrite Bead                                                After Ferrite Bead

                      Figure 6-47. PSRR vs Frequency                                            Figure 6-48. PSRR vs Frequency

14     Submit Document Feedback                                                                           Copyright © 2021 Texas Instruments Incorporated

                                                        Product Folder Links: TPS62912 TPS62913

                                                                                                                  TPS62912, TPS62913
www.ti.com                                                                                    SLVSFP4B – AUGUST 2020 – REVISED MARCH 2021

6.6 Typical Characteristics (continued)

                              VIN = 5 V                                                           VIN = 5 V

      Figure 6-49. High-Side RDS(ON) vs Junction Temperature                Figure 6-50. Low-Side RDS(ON) vs Junction Temperature

                              1 MHz, 2 A                                      5 VIN to 0.8 VOUT                   1 MHz

          Figure 6-51. FB Pin Voltage Error vs Input Voltage                      Figure 6-52. Output Voltage Error vs Load

         12 VIN to 0.8 VOUT                       1 MHz                            12 VIN                         1 MHz

              Figure 6-53. Output Voltage Error vs Load                        Figure 6-54. Oscillator Frequency vs Temperature

Copyright © 2021 Texas Instruments Incorporated                                                            Submit Document Feedback     15
                                                    Product Folder Links: TPS62912 TPS62913

TPS62912, TPS62913
SLVSFP4B – AUGUST 2020 – REVISED MARCH 2021                                                                                 www.ti.com

6.6 Typical Characteristics (continued)

            12 VIN                      2.2 MHz                                         VIN: 3 V, 5 V, 12 V

        Figure 6-55. Oscillator Frequency vs Temperature                  Figure 6-56. Shutdown Current vs Temperature

                                          VIN: 12 V                        25°C

                                  Figure 6-57. Output Discharge Resistance vs Output Voltage

16    Submit Document Feedback                                                               Copyright © 2021 Texas Instruments Incorporated

                                              Product Folder Links: TPS62912 TPS62913

                                                                                                                                                        TPS62912, TPS62913
www.ti.com                                                                                                              SLVSFP4B – AUGUST 2020 – REVISED MARCH 2021

7 Detailed Description
7.1 Overview
The TPS6291x low-noise, low-ripple synchronous buck converter is a fixed frequency current mode converter.
The converter has a filtered internal reference to achieve a low-noise output similar to low-noise LDOs. The
converter achieves lower output voltage ripple by using a switching frequency of either 2.2 MHz or 1 MHz and a
larger inductance. The output voltage ripple can be further reduced by adding a small second stage L-C filter to
the output. This can be a ferrite bead or a small inductor, followed by an output capacitor. Internal compensation
maintains stability with an external filter inductor up to 50 nH. To avoid voltage drops across this second stage
filter, the device regulates the output voltage after the filter. The TPS6291x family supports an optional spread
spectrum modulation. For example, when powering ADCs, spread spectrum modulation reduces the mixing
spurs. Switching frequency, spread spectrum modulation, and output discharge are set using the S-CONF pin.
7.2 Functional Block Diagram
                                                                                                      PG                                                     VIN

                                                                                                                                      High Side
                                                                                                                                    Current Sense
                                                                          VPG     +

                                                                          VFB     t

                                                                                                                   Slope
                                                               Undervoltage
EN/SYNC                                +                                                                        Compensation             G
                                                                  lockout
                              1.0V     t                     Thermal shutdown
                 RPD

                                            Clock
                                           Detector

                                                                            MUX                            MOSFET Driver
                                                                                                         Anti Shoot Through
                             EN/SYNC                                                                   Converter Control Logic                                       SW

                 MODE                                             1MHz/2.2MHz
                                Spread Spectrum                            MODE
                                  Modulation                                                                                                   Low Side
                                                                                                                                             Current Sense

                                                                                                                                                                      PGND

                       VIN
                                                                                            Comparator

                                                                                                                                               2nd stage filter       FB
                                                                                                                                t              compensation
                                                                                                                           GM
                             Start-up readout                                                                                   +
                                                                                                                                                                      VO
                                                       S-CONF                                   VIN
 S-CONF                              ADC              Register                  MODE
                                                      Selection                                                        GM Amplifier
                                                                                                       INR/SS

                                                                                                      Softstart

                                                                                       Rf                                                                    RDIS
                                                                        VREF
                                                                        0.8V
                                                                                                                                       Output voltage
                                                                                                                    MODE                 discharge
                                                                                                                                            logic

                                                      PSNS                                    NR/SS

Copyright © 2021 Texas Instruments Incorporated                                                                                              Submit Document Feedback      17
                                                                  Product Folder Links: TPS62912 TPS62913

TPS62912, TPS62913
SLVSFP4B – AUGUST 2020 – REVISED MARCH 2021                                                                            www.ti.com

7.3 Feature Description
7.3.1 Smart Config (S-CONF)
This S-CONF pin configures the device based on the resistor value. This pin is read after EN/SYNC goes high.
The device configuration cannot be changed during operation. The S-CONF value is re-read if EN is pulled
below 200 mV or if VIN falls below UVLO. Table 7-1 shows the configuration options of the following:
•    Switching frequency
•    Spread spectrum modulation
•    Output discharge
•    Synchronization
                                  Table 7-1. S-CONF Device Configuration Modes
                    SWITCHING                                         OUTPUT
     S-CONF                             SPREAD SPECTRUM                                       SYNCHRONIZATION
                    FREQUENCY                                       DISCHARGE
      VIN             2.2 MHz                     OFF                   OFF                             No
      GND              1 MHz                      OFF                   OFF                             No
     4.87 kΩ          2.2 MHz                     OFF                   OFF                   1.9 MHz to 2.42 MHz
     6.04kΩ           2.2MHz                     Triangle               OFF                             No
     7.5 kΩ           2.2 MHz                    Random                 OFF                             No
     9.31 kΩ           1 MHz                      OFF                   OFF                    0.9 MHz to 1.2 MHz
     11.5kΩ            1MHz                      Triangle               OFF                             No
     14.3 kΩ           1 MHz                     Random                 OFF                             No
                                                                    Discharge On
     18.2 kΩ          2.2 MHz                     OFF                    ON                             No
     22.1 kΩ           1 MHz                      OFF                    ON                             No
     27.4 kΩ          2.2 MHz                     OFF                    ON                   1.9 MHz to 2.42 MHz
      34kΩ            2.2MHz                     Triangle                ON                             No
     42.2 kΩ          2.2 MHz                    Random                  ON                             No
     52.3 kΩ           1 MHz                      OFF                    ON                    0.9 MHz to 1.2 MHz
     64.9kΩ            1MHz                      Triangle                ON                             No
     80.6 kΩ           1 MHz                     Random                  ON                             No

7.3.2 Device Enable (EN/SYNC)
The device is enabled by pulling the EN/SYNC pin high, and has an accurate rising threshold voltage of typically
1.01 V. Once the device is enabled, the operation mode is set by the configuration of the S-CONF pin. This
occurs during the device start-up delay time tdelay. Once tdelay expires, the internal soft-start circuitry ramps
up the output voltage over the soft-start time set by the CNR/SS capacitor. The start-up delay time tdelay varies
depending on the selected S-CONF value. It is shortest with smaller S-CONF resistors.
The EN/SYNC pin has an active pulldown resistor RPD. This prevents an uncontrolled start-up of the device, in
case the EN/SYNC pin cannot be driven to a low level. The pulldown resistor is disconnected after start-up. With
EN set to a low level, the device enters shutdown and the pulldown resistor is activated again.
7.3.3 Device Synchronization (EN/SYNC)
The EN/SYNC pin is also used for device synchronization. Once a clock signal is applied to this pin, the device
is enabled and reads the configuration of the S-CONF pin. The external clock frequency must be within the
clock synchronization frequency range set by the S-CONF pin. When the clock signal changes from a clock to a
static high, then the device switches from external clock to internal clock. To shutdown the device when using an
external clock, EN/SYNC must go low for at least 10 µs.

18     Submit Document Feedback                                                         Copyright © 2021 Texas Instruments Incorporated

                                              Product Folder Links: TPS62912 TPS62913

                                                                                                                       TPS62912, TPS62913
www.ti.com                                                                                         SLVSFP4B – AUGUST 2020 – REVISED MARCH 2021

The clock signal can be a logic signal with a logic level as specified in the electrical table, and can be applied
directly to the EN/SYNC pin. External logic, such as an AND gate, can be used to combine separate enable and
clock inputs, as shown in Figure 7-1.

                                                                                  TPS6291x
                                                              EN
                                                                                   EN/SYNC
                                                             CLK

                                     Figure 7-1. Synchronization with Separate Enable Signal (optional)

7.3.4 Spread Spectrum Modulation
Using the S-CONF pin enables or disables spread spectrum modulation. DC/DC converters generate an output
voltage ripple at the switching frequency. When powering ADCs or an analog front end (AFE), the switching
frequency generates high frequency mixing spurs as well as a low frequency spur in the output frequency
spectrum. Using the optional second stage L-C filter reduces the ripple of the converter and spurs by up to 30
dB.
The device has integrated two different spread spectrum modulation (SSM) schemes that are selected by
the resistor connected to the S-CONF pin acording to Table 7-1. It is possible to select random or triangle
modulation to spread the switching frequency over a larger frequency range. The triangular SSM is modulated
based on the switching frequency, and results in 1.9 kHz for 1 MHz switching frequency and 4.3 kHz for
2.2 MHz switching frequency. The modulation spread is ±10% of the device switching frequency. This SSM
provides high attenuation when the receiver bandwidth is less than the modulation frequency, typically the
case for systems using Fast Fourier Transforms (FFT) post processing as in high speed ADC applications.
For applications sensitive to noise at the modulation frequency, random SSM is used. Using a random spread
spectrum modulation also reduces the spurs in the output spectrum as shown in Figure 6-2. The random
SSM operates with the same frequency spread and modulation period as the triangular SSM. The randomized
modulation uses a Fibonacci Linear-Feedback Shift Register (LFSR) so that every tone is generated once during
the pseudo-random generation period. The frequency spreading is shown in Figure 7-2.The attenuation using
random or triangle SSM is shown in Figure 6-28.

                                                                                                  fSW
                                                                                             Unmodulated
                                                                Spectral envelope of         (single tone)
                                                                triangular modulation
                                                                     (+/- 10% fSW)
                          Amplitude (dB)

                                                                Spectral envelope of
                                                                random modulation
                                                                   (+/- 10% fSW)

                                                 fMOD
                                              Triangular
                                             (single tone)    Increased noise floor
                                                             with random modulation

                                                   Figure 7-2. Spread Spectrum Modulation

7.3.5 Output Discharge
Output discharge is enabled or disabled, depending on the S-CONF setting. With output discharge enabled,
the output voltage is pulled low by a discharge resistor RDIS of typically 7 Ω. The output discharge function is
enabled during thermal shutdown, UVLO, or when EN/SYNC is pulled low.

Copyright © 2021 Texas Instruments Incorporated                                                                 Submit Document Feedback     19
                                                         Product Folder Links: TPS62912 TPS62913

TPS62912, TPS62913
SLVSFP4B – AUGUST 2020 – REVISED MARCH 2021                                                                                www.ti.com

7.3.6 Undervoltage Lockout (UVLO)
To avoid mis-operation of the device at low input voltages, the device is enabled once the input voltage is above
the undervoltage lockout threshold. The device is disabled once the input voltage falls below the undervoltage
threshold.
7.3.7 Power-Good Output
The device has a power-good output. The PG pin goes high impedance once the FB pin voltage is above 95%
of the nominal voltage, and is driven low once the voltage falls below typically 90% of the nominal voltage. Table
7-2 shows the typical PG pin logic. The PG pin is an open-drain output and is specified to sink up to 10 mA. The
power-good output requires a pullup resistor connecting to any voltage rail less than 18 V. The PG signal can be
used for sequencing of multiple rails by connecting to the EN pin of other converters. If not used, the PG pin can
be left floating or connected to GND. PG has a deglitch time of typically 8 μs before going low.
                                              Table 7-2. Power Good Pin Logic
                                                                                                   PG LOGIC STATUS
                                   DEVICE STATE
                                                                                        HIGH IMPEDANCE                  LOW
                                                     VFB ≥ VPG                                 √
     Enabled (EN/SYNC = High)
                                                 VFB < VPG after tPG                                                       √
     Shutdown (EN/SYNC = Low)                                                                                              √
                  UVLO                          0.7 V < VIN < VUVLO                                                        √

         Thermal Shutdown                            TJ > TJSD                                                             √

       Power Supply Removal                         VIN < 0.7 V                                √

7.3.8 Noise Reduction and Soft-Start Capacitor (NR/SS)
A capacitor connected to this pin reduces the low frequency noise of the converter and sets the soft-start time.
The larger the capacitor, the lower the noise and the longer the start-up time of the converter. A 470-nF capacitor
is typically connected to this pin for a start-up time of 5 ms, although longer and shorter start-up times can be
used. During soft start with a light load, the device skips switching pulses as needed to not discharge the output
voltage. The device can start into a pre-biased output voltage.
The device achieves low noise by adding an R-C filter to the reference voltage, as shown in Section 7.2. During
start-up, the NR/SS capacitor is charged with a constant current of 75 µA (typ) to 0.8 V. Larger NR/SS capacitors
provide for lower low frequency noise, as shown in Figure 6-29. The maximum NR/SS cap is 3.3 µF for a
start-up time of 35 ms. The minimum start-up time is set internally to 0.7 ms, which occurs when there is a small
NR/SS capacitor or no NR/SS capacitor.
7.3.9 Current Limit and Short Circuit Protection
The device is protected against short circuits and overcurrent. The switch current limit prevents the device from
high inductor current and from drawing excessive current from the input voltage rail. Excessive current can occur
with a shorted/saturated inductor or a heavy load/shorted output circuit condition. If the inductor current reaches
the threshold ISWpeak, the high-side MOSFET is turned off and the low-side MOSFET is turned on to ramp down
the inductor current. The high-side MOSFET is turned on again only when the low-side current is below the
low-side sourcing current limit ISWvalley.
Due to internal propagation delay, the actual current can exceed the static current limit, especially if the input
voltage is high and very small inductances are used. The dynamic current limit is calculated as follows:

                              § VL ·
       Ipeak (typ )   ISWpeak ¨ ¸ u tPD
                              ©L¹                                                                                              (1)

where
•     ISWpeak is the static current limit, specified in Section 6.5

20      Submit Document Feedback                                                            Copyright © 2021 Texas Instruments Incorporated

                                              Product Folder Links: TPS62912 TPS62913

                                                                                                                TPS62912, TPS62913
www.ti.com                                                                                  SLVSFP4B – AUGUST 2020 – REVISED MARCH 2021

•    L is the inductance
•    VL is the voltage across the inductor (VIN - VOUT)
•    tPD is the internal propagation delay, typically 50 ns
The low-side MOSFET also contains a negative current limit to prevent excessive current from flowing back
through the inductor to the input. If the low-side sinking current limit is exceeded, the low-side MOSFET is turned
off. In this scenario, both MOSFETs are off until the start of the next cycle.
7.3.10 Thermal Shutdown
The device goes into thermal shutdown once the junction temperature exceeds typically 170°C with a 20°C
hysteresis.
7.4 Device Functional Modes
7.4.1 Fixed Frequency Pulse Width Modulation
To minimize output voltage ripple, the device operates in fixed frequency PWM operation down to no load. The
switching frequency of 1 MHz or 2.2 MHz is selected using the S-CONF pin.
7.4.2 Low Duty Cycle Operation
For high input voltages or low output voltages, the 70-nsec minimum on-time limits the maximum input to output
voltage difference and the switching frequency selected. When the minimum on-time is reached, the output
voltage rises above the regulation point. Refer to Table 8-2 for detailed design recommendations.
7.4.3 High Duty Cycle Operation (100% Duty Cycle)
The device offers a low input-to-output voltage differential by entering 100% duty cycle mode. In this mode,
the high-side MOSFET switch is constantly turned on. The minimum input voltage to maintain output voltage
regulation, depending on the load current and the output voltage level, is calculated as:

      VIN (min) VOUT (min) IOUT u (RDS (ON ) RL)                                                                               (2)

where
• VOUT(min) is the minimum output voltage the load can accept
• IOUT is the output current
• RDS(ON) is the RDS(ON) of the high-side MOSFET
• RL is the DC resistance of the inductor used
To maintain fixed frequency switching, the device requires a minimum off-time of 50 ns (typ), 60 ns (max). If this
limit is reached during a switching pulse, the device skips switching pulses to maintain output voltage regulation.
If the input voltage decreases further, the device enters 100% mode.
7.4.4 Second Stage L-C Filter Compensation (Optional)
Most low-noise and low-ripple applications use a ferrite bead and bypass capacitor before the load. Using a
second L-C filter is especially useful for low-noise and low-ripple applications with constant load current such as
ADCs, DACs, and Jitter Cleaner. The second stage L-C filter is optional, and the device can be used without
this filter. Without the filter, the device has a low output voltage noise of typically 16.9 μVRMS shown in Figure
6-37 with an output voltage ripple of 280 μVRMS shown in Figure 6-12. The second stage L-C filter attenuates
the output voltage ripple by another approximately 30 dB shown in Figure 6-14. To improve load regulation, the
device can remote sense the output voltage after the second stage L-C filter and is internally compensated for
the additional double pole generated by the L-C filter.
To keep the second stage L-C filter as small as possible, the internal compensation is optimized for a 10-nH
to 50-nH inductance. A small ferrite bead or even a PCB trace provides sufficient inductance for output voltage
ripple filtering. See Section 8.2.2.2.4 for details.

Copyright © 2021 Texas Instruments Incorporated                                                          Submit Document Feedback     21
                                                  Product Folder Links: TPS62912 TPS62913

TPS62912, TPS62913
SLVSFP4B – AUGUST 2020 – REVISED MARCH 2021                                                                                            www.ti.com

8 Application and Implementation
                                                                  Note
        Information in the following applications sections is not part of the TI component specification,
        and TI does not warrant its accuracy or completeness. TI’s customers are responsible for
        determining suitability of components for their purposes, as well as validating and testing their design
        implementation to confirm system functionality.

8.1 Application Information
The TPS6291x family of devices are optimized for low noise and low output voltage ripple.
8.2 Typical Applications
                                                                L1                            Lf
                                            TPS62913
                                                              2.2µH                          10nH
           Vin                           VIN           SW                                                                           Vo
           12V                                                                                                                   1.2V/3A
                                         EN/SYNC       VO                             COUT
              CIN       C1                                                           3x22µF
                                                                                                  R1        CFF
            2x10µF     2.2nF             S-CONF        FB                                                   N/P
                                  R4                                                             2.49k
                                 52.3k                                                                                Cf
                                         PSNS       NR/SS                                                           2x22µF
                                                                     Vo         CNR/SS               R2
                                         PGND         PG
                                                                                470nF               4.87k
                                                               R3
                                                              100k

                                                   Figure 8-1. Typical Schematic

Table 8-1 shows the list of components for the application curves in Section 8.2.3, unless otherwise noted.
                                                   Table 8-1. List of Components
      REFERENCE                     PART NUMBER                                DESCRIPTION                          MANUFACTURER(1)
                                                                      Low Noise and low ripple buck
        TPS62913        TPS62913                                                                                      Texas Instruments
                                                                               converter
            L1          XGL4030-222MEC or XGL4030-472MEC                  Inductor: 2.2 μH or 4.7 μH                       Coilcraft
                                                                 Ceramic capacitors: 2 × 10 µF ±10%
           CIN          C2012X7S1E106K125AC                                                                                  TDK
                                                                  25-V ceramic capacitor X7S 0805
                                                                  Ceramic capacitors: 3 × 22 µF, 10 V,
          COUT          C2012X7S1A226M125AC                                                                                  TDK
                                                                          ±20%, X7S, 0805
            Lf          BLE18PS080SN1                                           Ferrite Bead                                MuRata
                                                                  Ceramic capacitor: 2 × 22 µF, 10 V,
            Cf          C2012X7S1A226M125AC                                                                                  TDK
                                                                          ±20%, X7S, 0805
           C1           GRM155R71H222KA01D                           Ceramic capacitor: 2200 pF, 50 V,                      MuRata
                                                                            ±10%, X7R, 0402
       CNR/SS, CFF                                                           Ceramic capacitor                             Standard
      R1, R2, R3, R4                                                              Resistor                                 Standard

(1)     See the Third-Party Porducts Disclaimer

8.2.1 Design Requirements
The external components have to fulfill the needs of the application, but also meet the stability criteria of the
control loop of the device. The device is optimized to work within a range of external components, and can be
optimized for the following:

22      Submit Document Feedback                                                                        Copyright © 2021 Texas Instruments Incorporated

                                                  Product Folder Links: TPS62912 TPS62913

                                                                                                                                TPS62912, TPS62913
www.ti.com                                                                                      SLVSFP4B – AUGUST 2020 – REVISED MARCH 2021
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

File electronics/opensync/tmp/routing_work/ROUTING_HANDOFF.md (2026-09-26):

# OpenSync routing handoff

Saved project: `opensync.kicad_pcb` in this KiCad project directory.

## Final verification

- Native KiCad DRC, including all track errors, zone refill, and schematic parity: **0 errors, 0 unconnected items, 0 schematic parity issues**.
- **63 pre-existing silkscreen/text warnings remain**: 29 overlaps, 25 silk-over-copper, 4 silk-to-edge, and 5 text-height warnings. Their item identities match the original board's warnings; they were not excluded or downgraded.
- Independently compared all 678 schematic-assigned PCB pads against the updated hierarchical schematic netlist: no mismatches.
- Preserved all 221 footprints' pad geometry, pad numbering, drills, layers, shapes, relative pad positions, component values, fields, and 3D models. The four USB pad-net updates below are the only electrical pad-assignment changes.
- Board outline and MCU position unchanged. Existing non-USB copper net assignments, widths, and layers preserved.
- ERC is unchanged: one pre-existing D14 library-symbol mismatch warning, no new ERC findings.

This completes the requested copper routing, not fabrication sign-off. The remaining silkscreen warnings still require review. No field-solver certification, electrical simulation, or hardware validation was performed.
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

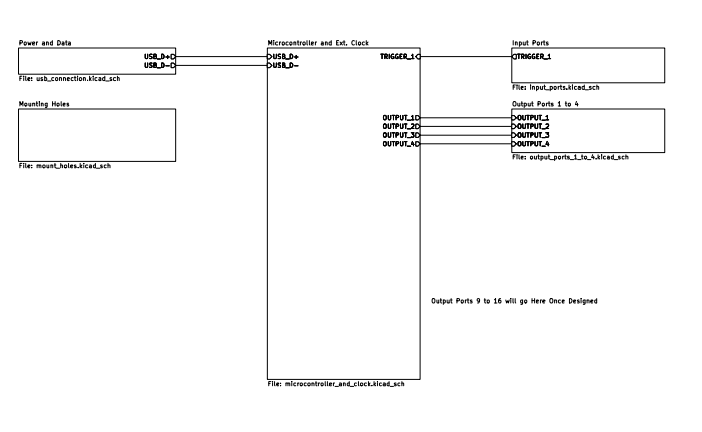
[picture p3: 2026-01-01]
documents/SDLC/4_development/assets/images/root_pcb_schematic.png

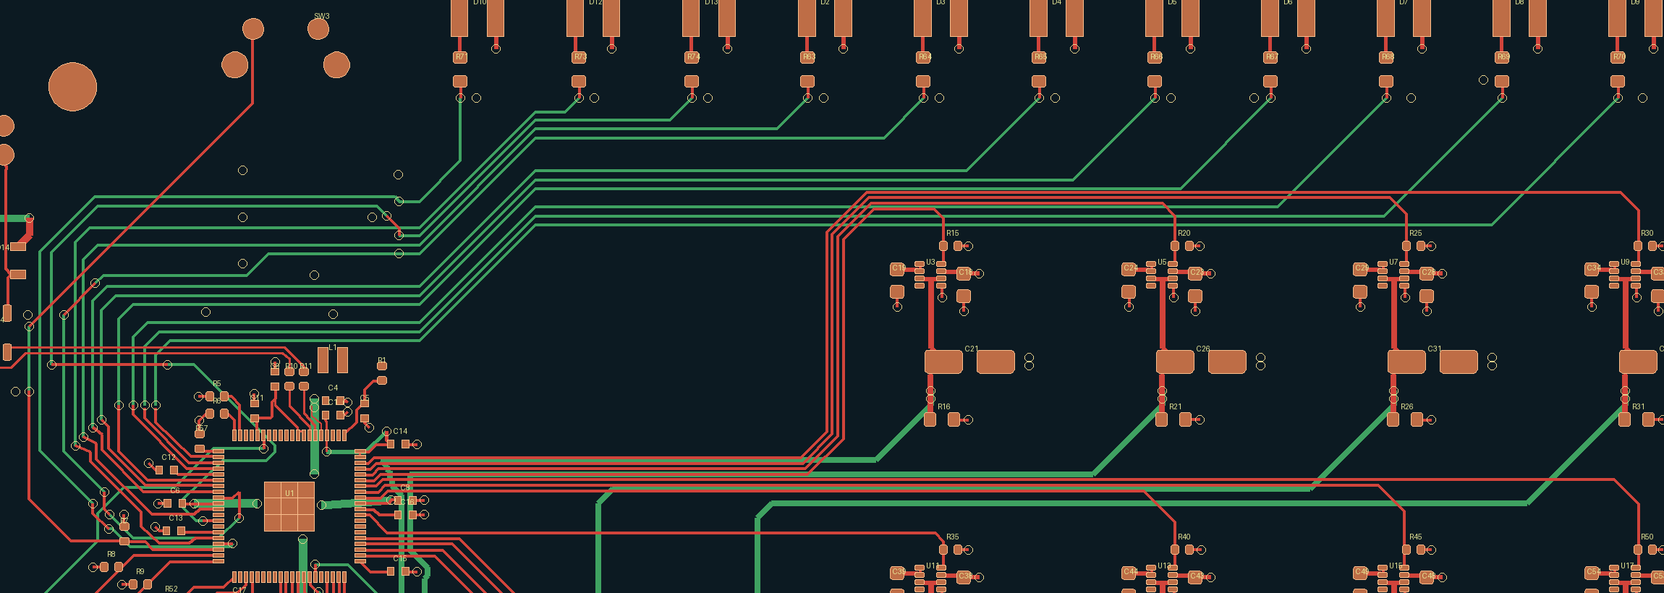
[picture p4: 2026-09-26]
electronics/opensync/tmp/led_route_cleanup_20260918/agent-entry-vias.png

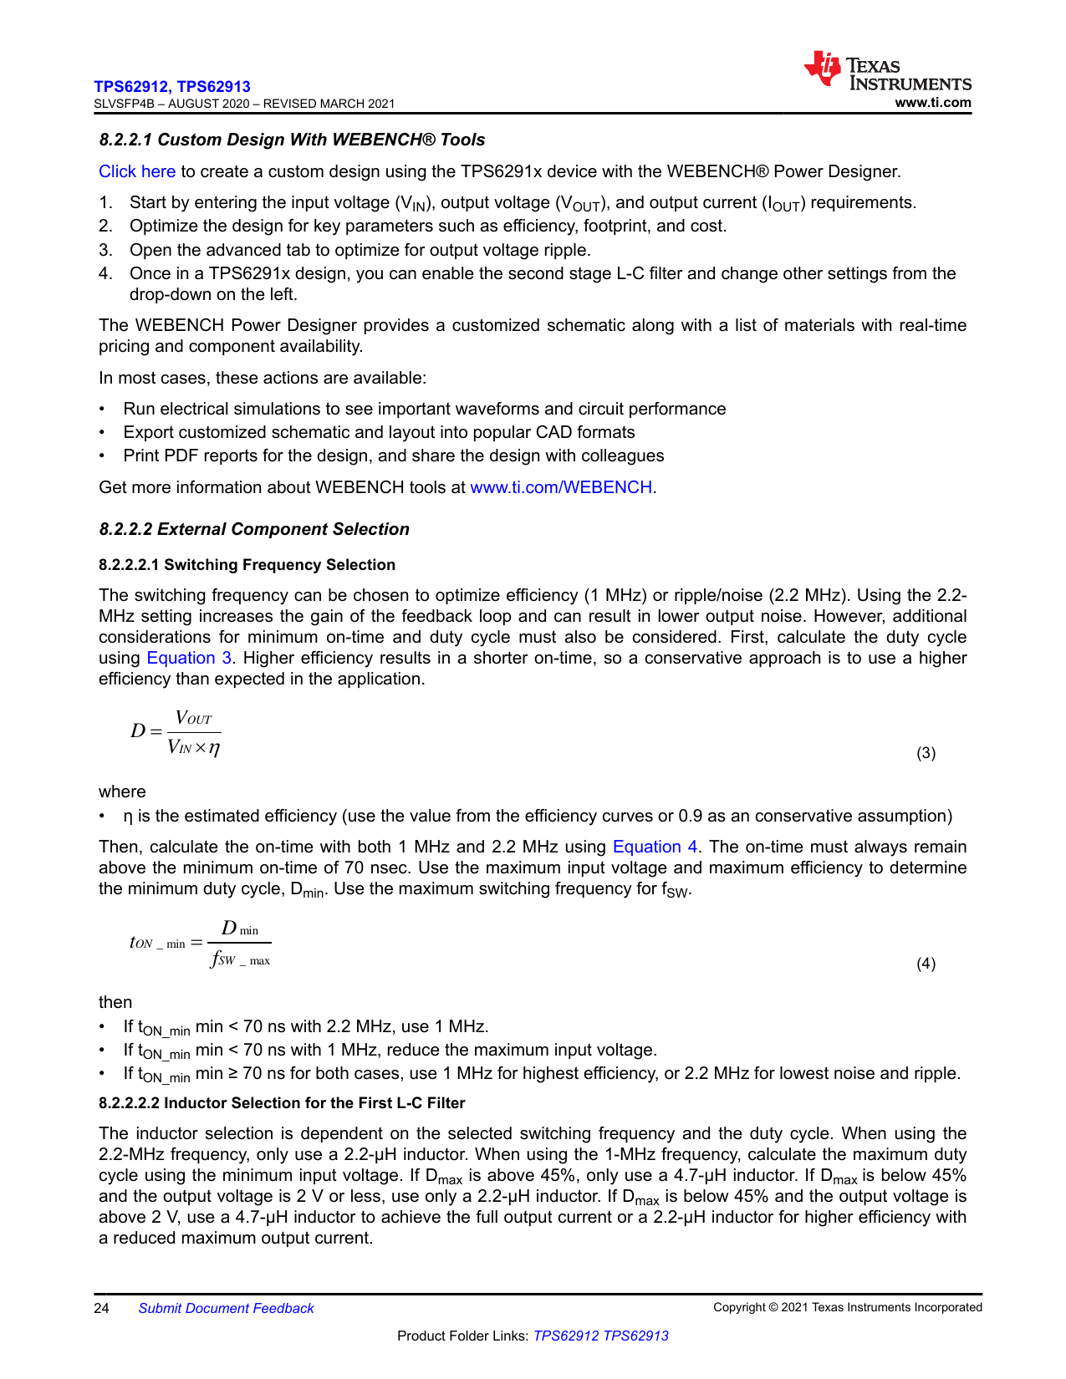
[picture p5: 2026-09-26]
electronics/opensync/tmp/pdfs/tps62912-app-24.png

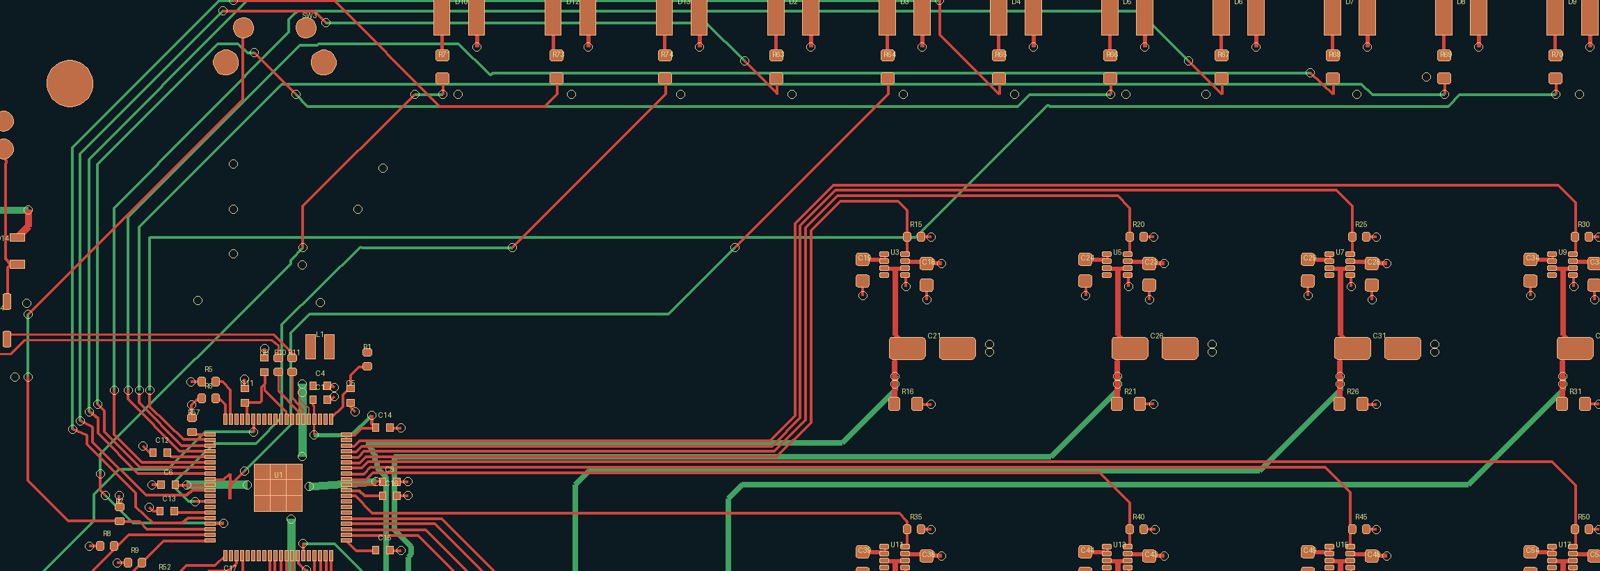
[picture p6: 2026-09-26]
electronics/opensync/tmp/led_route_cleanup_20260918/agent-desc.png

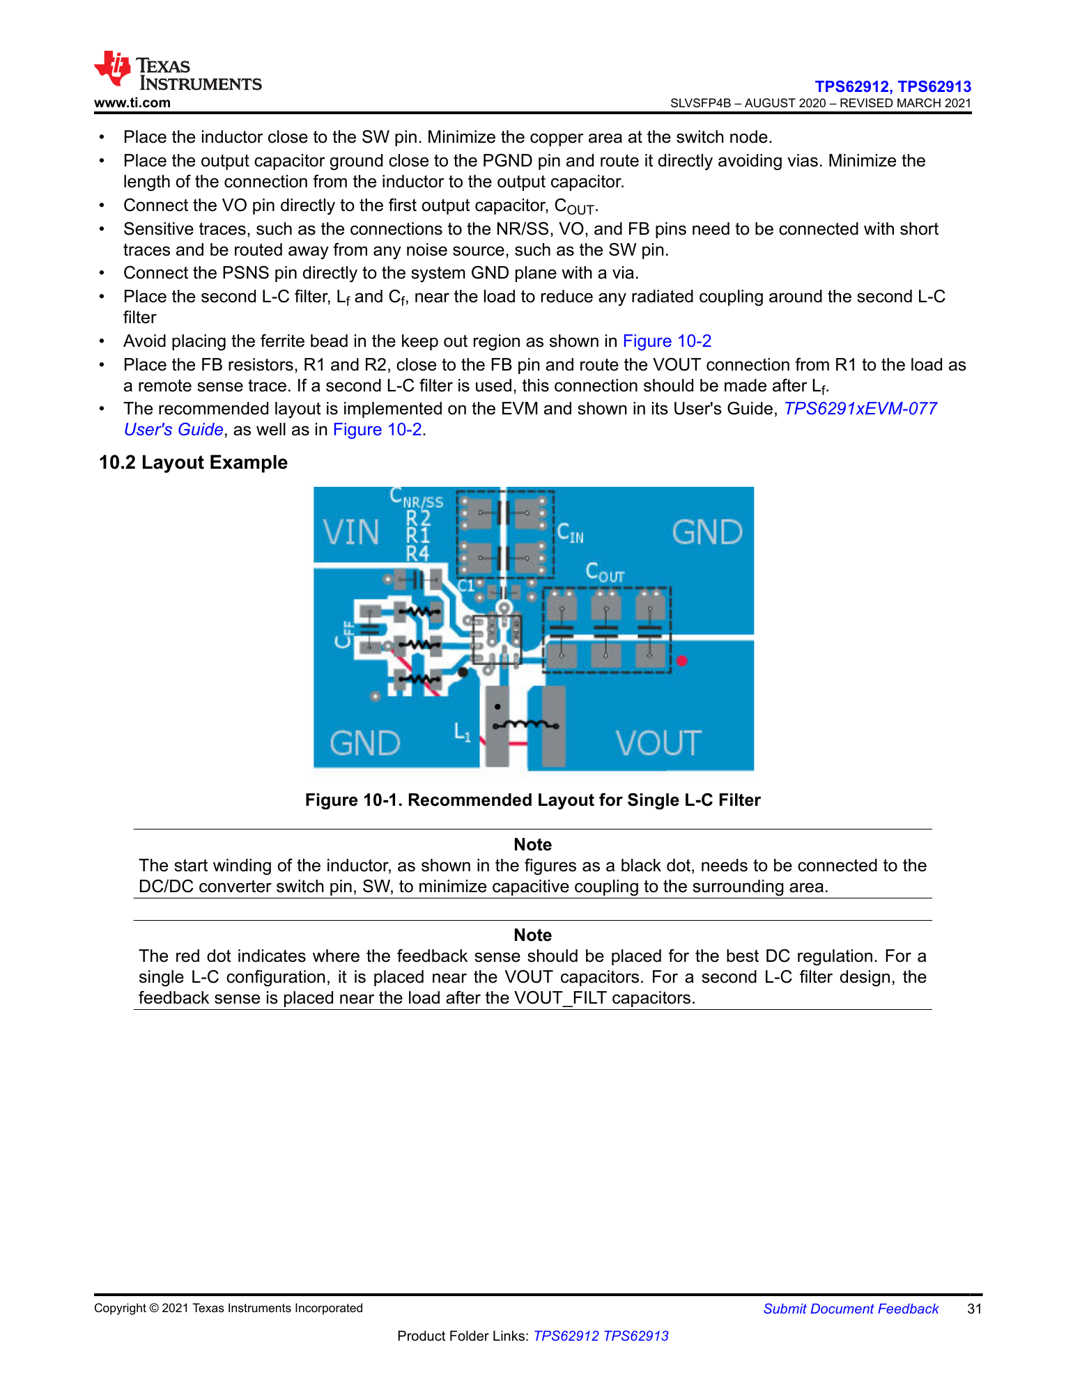
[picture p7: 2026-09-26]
electronics/opensync/tmp/pdfs/tps62912-layout-31.png

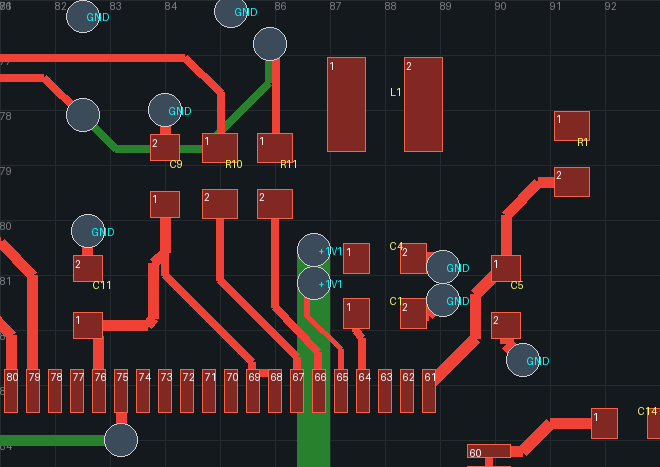
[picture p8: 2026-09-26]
electronics/opensync/tmp/routing_digital_review/mcu_candidate.png

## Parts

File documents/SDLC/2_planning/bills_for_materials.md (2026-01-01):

# Bill for Materials

## Version History
| Date | Version | Change | 
| --- | --- | --- |
| 9/10/2025 | 0.1.0 | Intitial publishment. |
| 10/24/2025 | 0.1.0 | Obtained oscilliscope. |
| 12/31/2025 | 0.2.0 | Obtained other electronics. |

## Executive Summary
In order to better facilitate the design and construction of a novel open source synchronizing device, it is important to identify equipment and materials that may be required to ensure that the project runs smoothly and successfully. Since this project includes both software and hardware aspects, it would be beneficial to list necessary equipment and materials due to its tight budget. As such, a table of (would be) aquired equipment and materials is presented in this document.

## Bill for Materials
| Equipment/Material] | Cost (USD) Each/Total | Aquired | Desription | Justification | 
| --- | --- | --- | --- | --- |
| Siglent SDS804X-HD | $428.00 | Yes | 4-channel 70 MHz osciliscope | Verification of pulse timing and oepration; easy to hack to 200 MHz |
| 3D Printer | N/A | Yes | Filament and 12k resin 3D-printer | Fabrication of electrical housing and mounts |
| Atten ST-990 Soldering Station | $110.00 | Yes | Soldering station | It's cheap; needed for soldering connectors |
| Amphenol MUSBD511N1 | $12.30$ | Yes | USB Type B Connector | Secure USB connection for serial interfacing |
| Wurth Elektronik SMB Connectors | $6.53/$$81.48 | Yes | 15x 50 Ohm SMB connectors | I like the look of them |

### Expected minimum bill total: $631.6

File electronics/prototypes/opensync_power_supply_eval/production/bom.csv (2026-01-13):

Designator | Footprint | Quantity | Value | LCSC Part #
C1, C3, C4, C5 | 0402 | 4 | 10u | C1856484
C2 | 0402 | 1 | 4.7u | C326586
J1 | 61400416121 | 1 | 61400416121
L2 | IND_ASPI-4030S-150M-T | 1 | 15u | C5570254
L3 | IND_ASPI6045S220MT | 1 | 22u | C187454
TP1, TP2, TP3, TP4 | TestPoint_Pad_2.0x2.0mm | 4 | TestPoint
U1 | SOT-223-3_TabPin2 | 1 | NCP1117-3.3_SOT223 | C26537
U3 | Converter_DCDC_Murata_NXExSxxxxMC_SMD | 1 | NXE2S0505MC

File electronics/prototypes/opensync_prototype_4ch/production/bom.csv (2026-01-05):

Designator | Footprint | Quantity | Value | LCSC Part #
C1, C20, C4, C5 | 0402 | 4 | 4.7u | C326586
C10, C11, C12, C13, C14, C15, C16, C17, C23, C24, C25, C26, C27, C28, C29, C30, C31, C6, C8, C9 | 0402 | 20 | 100n | C60474
C18, C19, C21, C22 | 0402 | 4 | 10u | C1856484
C2, C3 | 0402 | 2 | 15p | C326803
C7 | 0402 | 1 | 4.7u | C60474
D1, D2 | 0603 | 2 | LED
J1 | 61400416121 | 1 | 61400416121
J12 | JST_SH_SM03B-SRSS-TB_1x03-1MP_P1.00mm_Horizontal | 1 | SM03B-SRSS-TB
J13, J2, J4, J5, J6, J7 | 61611042121502 | 6 | 61611042121502
L1 | L_pol_2016 | 1 | 3.3u | C42411119
L2 | IND_ASPI-4030S-150M-T | 1 | 15u | C5570254
L3 | IND_ASPI6045S220MT | 1 | 22u | C187454
R1 | 0402 | 1 | 33 | C844506
R10, R17, R18, R19, R20, R5, R6, R7 | 0402 | 8 | 10k | C71617
R11, R12 | 0402 | 2 | 27 | C4162575
R13 | 0402 | 1 | 470 | C482182
R14 | 0402 | 1 | 100
R2, R3, R4 | 0402 | 3 | 1k | C313354
R27, R28, R30, R32, R34, R8 | 0402 | 6 | 47k | C176117
R29, R31, R33, R35 | 0402 | 4 | 49.9 | C1858992
R9 | 0402 | 1 | 169
SW1, SW2 | SW_Push_1P1T_NO_Vertical_Wuerth_434133025816 | 2 | SW_Push
U1 | SOT-223-3_TabPin2 | 1 | NCP1117-3.3_SOT223 | C26537
U2 | RP2350-QFN-80-1EP_10x10_P0.4mm_EP3.4x3.4mm_ThermalVias | 1 | RP2354_80QFN | C39843328
U3 | Converter_DCDC_Murata_NXExSxxxxMC_SMD | 1 | NXE2S0505MC
U4 | SOT65P210X110-5N | 1 | SN74LVC1G17DCKR | C10425
U5, U6, U7, U8 | SOT65P210X110-6N | 4 | SN74LVC1T45DCKR | C9382
Y1 | XTAL_ABM8-272-T3 | 1 | ABM8-272-T3 | C20625731

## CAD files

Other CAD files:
hardware/emclosure_protoype.FCStd

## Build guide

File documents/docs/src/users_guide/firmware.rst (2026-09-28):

Firmware Guide
==============

The firmware runs on the Raspberry Pi Pico 2's RP2350 microcontroller. It
accepts SCPI commands over USB, stores system and channel settings, and
configures the PIO state machines that generate timing signals.

Install firmware from a release
-------------------------------

Compiled firmware will be included with the corresponding
`OpenSync GitHub release <https://github.com/ErichZimmer/OpenSync/releases>`_.
For normal installation, download the OpenSync **UF2** firmware asset attached
to the release you want to use. The release's source-code ZIP or tarball is
for building from source; it is not the file copied to the device for flashing.

Follow the flashing steps below once you have the UF2 file. Compiling the
firmware yourself is only needed when building a development checkout or
making changes to the source.

.. _opensync-flashing:

Flash the device
----------------

1. Close any PWA, Python session, or serial terminal connected to OpenSync,
   then unplug the device from USB.
2. Access the PCB's **BOOTSEL** button. Hold it while reconnecting USB,
   then release it when the bootloader drive appears.
3. Copy the release's UF2 file onto that drive. The bootloader normally
   identifies the drive as ``RP2350``.
4. Wait for the file copy to finish. The device reboots and the bootloader
   drive disappears.
5. Reconnect through the PWA or Python library and query ``*IDN?`` and
   ``:DEVice:STATus?`` to check device identity and state.

Raspberry Pi documents this process in its
`Pico-series SDK and UF2 instructions
<https://www.raspberrypi.com/documentation/microcontrollers/c_sdk.html>`_.

How the firmware is organized
-----------------------------

The current application is in ``firmware/opensync``. The older prototype
projects elsewhere in ``firmware`` are separate from this build.

.. list-table:: Firmware source layout
   :header-rows: 1
   :widths: 30 70

   * - Section
     - Responsibility
   * - ``src/main.c``
     - Starts the application by calling ``core_2_init()``.
   * - ``src/system/core_2.c``
     - Initializes the clock, status, USB serial transport, and SCPI interface.
       Launches the sequencer core and processes incoming commands.
   * - ``src/system/core_1.c``
     - Loads PIO programs, configures enabled sequencers, starts execution,
       waits for completion or an abort, and releases timing resources.
   * - ``src/serial/``
     - Defines the SCPI command interface, parameter parsing, validation,
       error handling, and device/system/sequencer callbacks.
   * - ``src/sequencer/``
     - Configures the internal clock, T0 event timer, external trigger/gate
       inputs, and output channels, including their PIO and DMA resources.
   * - ``src/pio_assembly/``
     - Contains the low-level PIO programs for the internal clock, T0,
       and output-channel waveforms.
   * - ``src/structs/``
     - Defines the stored SCPI settings and the structures used to configure
       clock and pulse sequencers.
   * - ``src/status/``
     - Holds sequencer and debug status shared by the firmware's two cores.
   * - ``src/overclock/``
     - Sets the system clock used by the timing engine.
   * - ``src/usb_desc/`` and ``src/version/``
     - Provide USB descriptors and firmware identification information.
   * - ``external/scpi-parser/`` and ``external/prawn_do/``
     - Supply the SCPI parser and USB serial transport used by the application.
   * - ``CMakeLists.txt`` and ``src/CMakeLists.txt``
     - Select the Pico board and SDK, compile the application and dependencies,
       generate PIO headers, and produce the UF2 firmware.

During operation, USB commands update the SCPI settings. A start request tells
the sequencer core to prepare the internal clock, T0, and enabled channels.
PIO state machines perform the timing while DMA supplies their data. The
sequencer core monitors completion and stop requests, then cleans up the
resources. A requested stop can leave the device in ``ABORTED``; this state
is distinct from an unexpected program failure.

Build from source
-----------------

Tools and dependencies
~~~~~~~~~~~~~~~~~~~~~~

Use the `Raspberry Pi Pico extension for Visual Studio Code
<https://github.com/raspberrypi/pico-vscode>`_ to manage the SDK and toolchain,
or provide the equivalent CMake, Ninja, Arm compiler, and Pico SDK setup.
The project's CMake configuration currently selects ``pico2`` and records
Pico SDK ``2.1.1``, toolchain ``14_2_Rel1``, and picotool ``2.1.1`` for the
extension-managed setup.

The SCPI parser is a Git submodule. From the OpenSync repository root, fetch
the revision recorded by the checkout:

.. code-block:: console

   git submodule update --init --recursive firmware/opensync/external/scpi-parser

Using Visual Studio Code
~~~~~~~~~~~~~~~~~~~~~~~~

1. Open or import ``firmware/opensync`` as an existing Pico project using the
   Raspberry Pi Pico extension.
2. Allow its SDK/toolchain setup to finish and confirm the target is Pico 2.
3. Run the extension's **Compile** action for the ``opensync`` target.
4. Locate ``opensync.uf2`` in the build output and follow :ref:`opensync-flashing`.

Using a terminal
~~~~~~~~~~~~~~~~

With the Pico SDK and Arm toolchain available, set ``PICO_SDK_PATH`` to your
SDK directory. From the repository root:

.. code-block:: console

   cmake -S firmware/opensync -B firmware/opensync/build -G Ninja -DPICO_BOARD=pico2
   cmake --build firmware/opensync/build --target opensync

For this build layout, the firmware file is
``firmware/opensync/build/src/opensync.uf2``. Copy it to the bootloader drive
using the same flashing procedure as a release UF2. CMake also produces
other build artifacts, but the UF2 is the one used for drag-and-drop flashing.

For individual device commands and timing parameters, see the
:doc:`API Reference <../api_reference/index>`.

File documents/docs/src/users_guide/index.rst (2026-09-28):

User Guide
==========

OpenSync is an open source synchronizer for particle image velocimetry (PIV)
and other laboratory measurements that depend on coordinated timing. Cameras,
pulsed illumination sources, and acquisition equipment must respond at known
times for their measurements to be useful. OpenSync provides a shared timing
reference and eight independently programmable output channels, allowing an
experiment's timing to be configured through a common device interface.

The project began with a practical barrier identified in the SDLC briefing
and feasibility study: commercial synchronizers can represent a substantial
cost for laboratories with limited funding. Simple custom microcontroller
solutions can reduce that cost, but often offer limited timing flexibility
or require firmware changes whenever an experiment's timing changes. OpenSync
exists to make a configurable synchronizer more accessible while keeping its
hardware and software available for inspection, modification, and reuse.

The design uses the Raspberry Pi RP2350's programmable input/output (PIO)
state machines to handle timing independently of the main processor's command
handling. The internal rate timer and individual output sequencers provide
configurable timing, synchronization, triggering, and gating. A USB SCPI
interface, Python library, and browser application let users change settings
without rewriting the timing firmware. The emphasis is on an affordable,
constructible device that supports a broad range of PIV measurements, rather
than reproducing every feature of a commercial instrument.

Hardware, firmware, and software
--------------------------------

.. toctree::
   :maxdepth: 1

   hardware
   firmware
   software

The Hardware Guide is reserved for building the physical device. The Firmware
Guide explains the code running on it, including release installation and
source compilation. The Software Guide covers Python, the PWA, and the
basic-operation notebooks.

Project background
------------------

This overview draws on the project's `requirements briefing
<https://github.com/ErichZimmer/OpenSync/blob/main/documents/SDLC/1_initalization/briefing.md>`_,
`feasibility study
<https://github.com/ErichZimmer/OpenSync/blob/main/documents/SDLC/1_initalization/feasibility.md>`_,
and `firmware revision planning
<https://github.com/ErichZimmer/OpenSync/blob/main/documents/SDLC/4_development/firmware_revision_planning.md>`_.
These SDLC documents record the design's evolution; early proposed channel
counts and configurations may differ from the current device.

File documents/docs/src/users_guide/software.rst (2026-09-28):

Software Guide
==============

OpenSync can be controlled from Python or from its browser-based progressive
web application (PWA). Both use the device's USB serial SCPI interface. The
Python library suits scripts, notebooks, and integration with an experiment;
the PWA provides a graphical editor and an interactive SCPI terminal.

Basic-operation notebooks
-------------------------

.. toctree::
   :maxdepth: 1

   ../notebooks/device_communication_basics
   ../notebooks/clock_setup
   ../notebooks/pulse_timing
   ../notebooks/scpi_pulse_basics

Python package
--------------

Installation
~~~~~~~~~~~~

The planned package installation command is:

.. code-block:: console

   pip install opensync

.. note::

   Package publication is planned. Use the development setup below until
   a release is available.

For current development, use an environment where this project's OpenSync
library is already installed, or make the repository's ``software`` directory
available on Python's import path. For example, from the repository root in
PowerShell:

.. code-block:: powershell

   $env:PYTHONPATH = (Resolve-Path software).Path

The library uses NumPy, Matplotlib, and pyserial. Activate the same Python
environment for your scripts and notebooks.

Connect and read device information
~~~~~~~~~~~~~~~~~~~~~~~~~~~~~~~~~~~

Connect OpenSync over USB, discover the available devices, and read the
identity and status of the first one:

.. code-block:: python

   import opensync

   ports = opensync.device_comm_search()
   if not ports:
       raise RuntimeError("No OpenSync device found. Check the USB connection.")

   with opensync.device_comm_managed(ports[0]) as device:
       print(opensync.device_system_version(device))
       print(opensync.device_system_status(device))

The context manager closes the connection when the block ends. This example
reads device information without starting a timing sequence.

Configure and run a sequence
~~~~~~~~~~~~~~~~~~~~~~~~~~~~

The normal Python workflow is:

1. Create clock and channel parameter dictionaries with ``get_clock_params()``
   and ``get_pulse_params()``.
2. Set timing, counters, synchronization, and enabled channels using the
   ``config_clock_*`` and ``config_pulse_*`` helper functions.
3. Inspect pulse timing with ``get_pulse_plot()`` when useful.
4. Open the serial connection and upload both configurations with
   ``device_params_load(device, clock_params, pulse_params)``.
5. Use ``device_system_fire()`` to start and ``device_system_stop()`` to stop.

The notebooks above work through the individual concepts. Function details
are in the :doc:`Python API Reference <../api_reference/index>`.

PWA
---

The OpenSync Synchronizer PWA is in ``software/pwa`` and uses the Arcane OS
SDK. Its interface groups the internal rate timer and trigger/gate controls
under **System**, with settings for outputs **CH A** through **CH H** below.

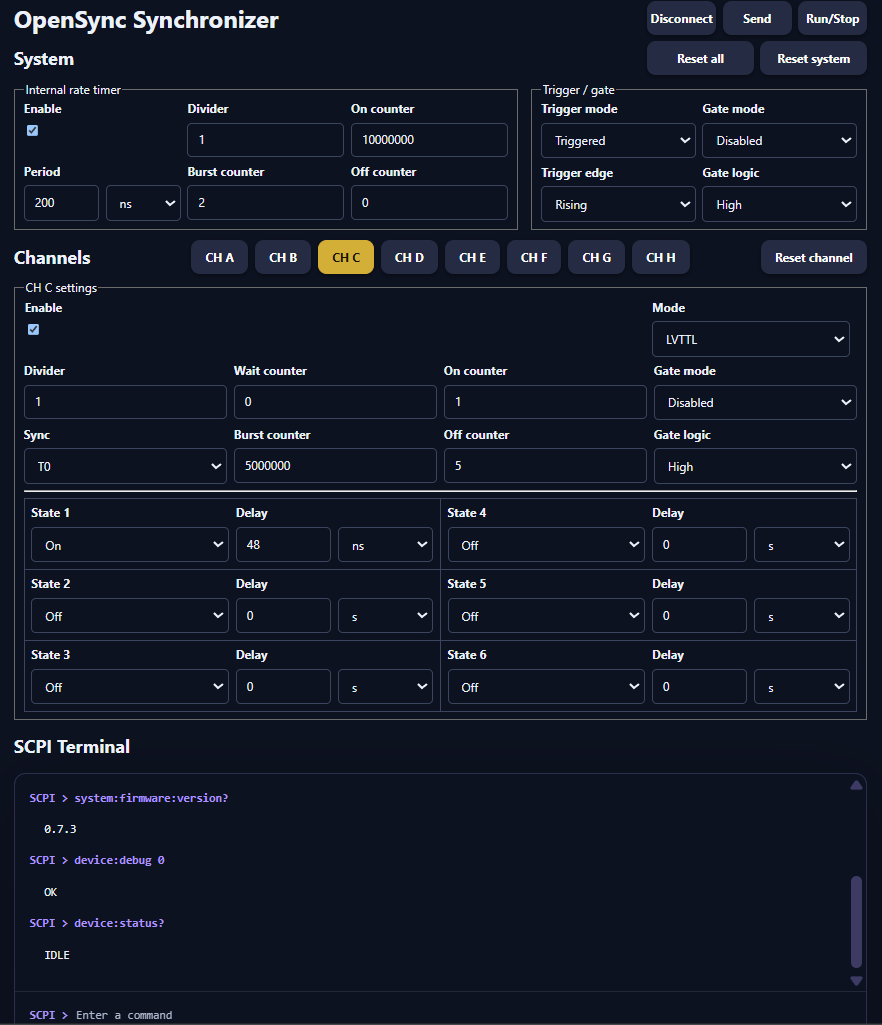
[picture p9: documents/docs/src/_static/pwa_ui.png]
OpenSync PWA with system timing controls, the channel C editor, and the SCPI terminal.


   OpenSync Synchronizer PWA: system settings, output-channel controls,
   and the SCPI terminal.

Run the PWA from the checkout
~~~~~~~~~~~~~~~~~~~~~~~~~~~~~

Use the Node.js version required by ``software/pwa/package.json`` (currently
``>=22.23.2``). From the repository root:

.. code-block:: console

   cd software/pwa
   npm ci
   npm run dev -- --app opensync-pwa --http --port 8000

Open the local URL printed by the server. Device access requires a browser
with Web Serial support, such as a supported desktop Chrome or Edge version.
Web Serial is available in secure contexts: use HTTPS when hosting the app;
loopback addresses such as ``http://127.0.0.1`` are suitable for local work.
See the `Web Serial documentation
<https://developer.chrome.com/docs/capabilities/serial>`_ for browser requirements.

Use the controls
~~~~~~~~~~~~~~~~

* **Connect / Disconnect** opens or closes the USB serial connection. Select
  OpenSync in the browser's serial-port chooser when prompted.
* **System** sets the internal rate timer, its counters, and trigger/gate modes.
* **CH A--CH H** selects the output channel whose settings you are editing.
* **Send** uploads the system and channel settings to the device.
* **Run/Stop** queries device status and requests a start or stop.
* **Reset all**, **Reset system**, and **Reset channel** restore the respective
  settings in the editor. Use **Send** to apply edited settings to the device.
* **SCPI Terminal** sends individual commands and displays responses.

Settings are stored locally in the browser through DBOPFS. Editing or saving
browser settings is separate from sending them to the device. Close the serial
connection before switching control between the PWA and a Python session.

Browser distribution
~~~~~~~~~~~~~~~~~~~~

To produce the browser package from ``software/pwa``:

.. code-block:: console

   npm run package -- --app opensync-pwa

The packaged application is written to ``dist/opensync-pwa``. Serve that
folder through an appropriate web host. On a supported browser, the PWA can
be installed as an application window using the browser's installation UI.

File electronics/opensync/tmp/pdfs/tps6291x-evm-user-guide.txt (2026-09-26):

www.ti.com                                                                                                                                                               Table of Contents

User’s Guide
TPS6291x Step-Down Converter Evaluation Module User's
Guide

                                                                                     ABSTRACT
The TPS6291xEVM-077 (BSR077) facilitates the evaluation of the TPS6291x 2-A and 3-A pin-to-pin compatible
Low Noise ( < 20 μVRMS) and Low Ripple ( < 10 μVRMS) buck converters in small 2-mm by 2-mm QFN packages.
The BSR077-003 uses the 3-A TPS62913 to output a 1.2-V output voltage from input voltages between 3 V
and 17 V. The BSR077-002 uses the 2-A TPS62912 to output a 3.3-V output voltage from input voltages up to
17 V. Due to its extremely low noise, the TPS6291x is a high-efficiency alternative to low-dropout (LDO) linear
regulators in noise-sensitive circuits, such as data converters, clocks, and amplifiers in telecom infrastructure,
medical, test and measurement, and aerospace and defense applications.

                                                                            Table of Contents
1 Introduction.............................................................................................................................................................................2
   1.1 Performance Specification................................................................................................................................................. 2
   1.2 Modifications...................................................................................................................................................................... 2
2 Setup........................................................................................................................................................................................5
   2.1 Input/Output Connector Descriptions................................................................................................................................. 5
   2.2 Ripple Measurement Setup................................................................................................................................................6
3 Test Results ............................................................................................................................................................................9
4 Board Layout ........................................................................................................................................................................10
5 Schematic and Bill of Materials...........................................................................................................................................13
   5.1 Schematic........................................................................................................................................................................ 13
6 Bill of Materials..................................................................................................................................................................... 14
A Ripple Measurements With Mis-oriented Inductor ...........................................................................................................15
Revision History.......................................................................................................................................................................17

                                                                                List of Figures
Figure 1-1. Loop Response Measurement Modification (Bottom Layer)..................................................................................... 3
Figure 1-2. Loop Response Measurement Modification (Top Layer)...........................................................................................4
Figure 3-1. Thermal Performance (VIN = 12 V, VOUT = 1.2 V, IOUT = 3000 mA, JP2 Open).........................................................9
Figure 3-2. Loop Response Measurement (VIN = 12 V, VOUT = 1.2 V, IOUT = 3000 mA, JP2 open)............................................ 9
Figure 4-1. Top Assembly.......................................................................................................................................................... 10
Figure 4-2. Top Layer.................................................................................................................................................................10
Figure 4-3. Internal Layer 1 .......................................................................................................................................................11
Figure 4-4. Internal Layer 2........................................................................................................................................................11
Figure 4-5. Bottom Layer .......................................................................................................................................................... 12
Figure 4-6. Bottom Layer (Mirrored).......................................................................................................................................... 12
Figure 5-1. TPS62913EVM-077 Schematic...............................................................................................................................13
Figure 5-2. TPS62912EVM-077 Schematic...............................................................................................................................13

                                                                                 List of Tables
Table 1-1. TPS62913EVM-077 Performance Specification Summary.........................................................................................2
Table 1-2. TPS62912EVM-077 Performance Specification Summary.........................................................................................2
Table 6-1. TPS6291xEVM-077 Bill of Materials.........................................................................................................................14

Trademarks
All trademarks are the property of their respective owners.

SLVUBX2B – AUGUST 2020 – REVISED MAY 2021                                                               TPS6291x Step-Down Converter Evaluation Module User's Guide                            1
Submit Document Feedback
                                                                  Copyright © 2021 Texas Instruments Incorporated

Introduction                                                                                                                         www.ti.com

1 Introduction
The TPS6291x family of devices are Low Noise, Low Ripple, synchronous, step-down converters in a small 2- ×
2- × 1-mm QFN package. Two different devices in this family support 2 A or 3 A of output current.
1.1 Performance Specification
Table 1-1 and Table 1-2 provides a summary of the TPS6291xEVM-077 performance specifications.
                              Table 1-1. TPS62913EVM-077 Performance Specification Summary
    Specification                   Test Conditions                                        MIN            TYP           MAX           Unit
    Input Voltage                   JP2 open or across 1 MHz and S-CONF                     3              12            17            V
    Output Voltage Setpoint                                                                                1.2                         V
    Output Current                                                                          0                             3            A
    S-CONF (R4) Setting             1 MHz with SYNC available, no spread                                  52.3                         kΩ
                                    spectrum, output discharge enabled

                              Table 1-2. TPS62912EVM-077 Performance Specification Summary
    Specification                   Test Conditions                                        MIN            TYP           MAX           Unit

    Input Voltage                                                                          3.5             12            17            V
    Output Voltage Setpoint                                                                                3.3                         V
    Output Current                                                                          0                             2            A
    S-CONF (R4) Setting             2.2 MHz with SYNC available, no spread                                27.4                         kΩ
                                    spectrum, output discharge enabled

1.2 Modifications
The printed-circuit board (PCB) for this EVM is designed to accommodate some modifications by the user.
Additional input and output capacitors can be added. Also, the input voltage at which the IC turns on can be
adjusted with two resistors, the soft start time and low frequency noise filtering can be changed, a feedforward
capacitor can be added, and the switching frequency, output discharge setting, and spread spectrum setting can
be changed. Finally, the loop response can be measured. See the device data sheet for details of the various
settings.

1.2.1 Input and Output Capacitors
C14 is provided for an additional input capacitor. This capacitor is not required for proper operation but can be
used to reduce the input voltage ripple.
C15, C17, and C18 are provided for additional bulk output capacitors. These capacitors are not required for
proper operation but can be used to reduce the output voltage ripple. The total output capacitance must
remain within the recommended range in the data sheet for proper operation. C16 and C19 are provided for
high-frequency bypass capacitors.

1.2.2 Configurable Enable Threshold Voltage
With JP1 removed, R6 and R7 can be installed to set a user-selectable input voltage at which the IC turns on.
1.2.3 NR/SS Capacitor
C9 sets the soft start time and the low frequency noise filtering. This capacitor can be changed to set other soft
start times and noise filtering levels.
1.2.4 Feedforward Capacitor
C13 is provided as a feedforward capacitor (CFF). Installing this capacitor can reduce the low-frequency noise,
especially for higher output voltages.

2        TPS6291x Step-Down Converter Evaluation Module User's Guide                                  SLVUBX2B – AUGUST 2020 – REVISED MAY 2021
                                                                                                                        Submit Document Feedback
                                                    Copyright © 2021 Texas Instruments Incorporated

www.ti.com                                                                                                                      Introduction

1.2.5 S-CONF Resistor
R4 selects the switching frequency, spread spectrum, output discharge, and clock synchronization settings. This
resistor can be changed and JP2 also selects different settings.
1.2.6 Loop Response Measurement
The loop response can be measured with simple changes to the circuitry. First, install a 49.9-Ω resistor across
R5's pads on the back of the PCB and install a 0-Ω resistor across R8's pads on the back of the PCB. The pads
are spaced to allow installation of a 0603-sized resistors. Second, cut the trace on the bottom layer below the
added 49.9-Ω resistor. Figure 1-1 shows these changes. Third, cut the short section of trace on the top layer
between the via on pin 3 and C4. Figure 1-2 shows this change. Lastly, replace the ferrite bead (FB1) with a
0-Ω resistor. The second LC filter must be removed to break the complete feedback loop and measure the loop
response. With these changes, an AC signal (10-mV, peak-to-peak amplitude recommended) can be injected
into the control loop across the added 49.9-Ω resistor. Figure 3-2 shows the results of this test.

                     Figure 1-1. Loop Response Measurement Modification (Bottom Layer)

SLVUBX2B – AUGUST 2020 – REVISED MAY 2021                                 TPS6291x Step-Down Converter Evaluation Module User's Guide     3
Submit Document Feedback
                                            Copyright © 2021 Texas Instruments Incorporated

Introduction                                                                                                                       www.ti.com

                           Figure 1-2. Loop Response Measurement Modification (Top Layer)

1.2.7 Single LC Filter Operation
For applications which do not require the lowest output voltage ripple, the TPS6291x may be operated without
the second LC filter. To operate with a single LC filter, replace FB1 with a 0-Ω resistor. C6 and/or C8 may
be removed to reduce the amount of output capacitance. The total output capacitance must remain within the
recommended range in the data sheet for proper operation.

4      TPS6291x Step-Down Converter Evaluation Module User's Guide                                  SLVUBX2B – AUGUST 2020 – REVISED MAY 2021
                                                                                                                      Submit Document Feedback
                                                  Copyright © 2021 Texas Instruments Incorporated

www.ti.com                                                                                                                              Setup

2 Setup
This section describes how to properly use the EVM.

2.1 Input/Output Connector Descriptions
 J1, Pin 1 and 2 – VIN            Positive input connection from the input supply for the EVM.

 J1, Pin 3 and 4 – S+/S-          Input voltage sense connections. Measure the input voltage at this point.

 J1, Pin 5 and 6 – GND            Return connection from the input supply for the EVM.

 J2, Pin 1 and 2 –                Filtered output voltage connection
 VOUT_FILT
 J2, Pin 3 and 4 – S+/S-          Output voltage sense connections. Measure the output voltage at this point.

 J2, Pin 5 and 6 – GND            Output return connection
 J3 – PG/GND                      The PG output is on pin 1 of this header with a convenient ground on pin 2.

 J4 – VOUT Ripple                 Use this SMA connector to measure the output voltage ripple before the second
 Measurement                      LC filter.

 J5 – VOUT_FILT Ripple            Use this SMA connector to measure the output voltage ripple after the second LC
 Measurement                      filter.

 JP1 – EN/SYNC                    EN/SYNC pin input jumper. Place the supplied jumper across ON and EN to turn
                                  on the IC. Place the jumper across OFF and EN to turn off the IC. Remove the
                                  jumper to set a configurable enable threshold voltage with R6 and R7.
                                  With the jumper removed, a clock signal can be applied on JP1 to synchronize
                                  the IC's switching. To allow the IC to accept the applied SYNC signal, the jumper
                                  on JP2 needs to be removed before applying the input voltage.

 JP2 – S-CONF                     S-CONF pin input jumper. Place the supplied jumper across 2.2 MHz and S-
                                  CONF to operate the IC with a 2.2-MHz switching frequency without spread
                                  spectrum or output discharge. Place the jumper across 1 MHz and S-CONF to
                                  operate the IC with a 1-MHz switching frequency without spread spectrum or
                                  output discharge. Remove the jumper to operate the IC with the S-CONF settings
                                  set by R4 and to allow clock synchronization.

                                                                         Note
                                        Set the JP2 jumper position before enabling the IC. Changing JP2 after
                                        enabling the IC has no effect.

                                                                          Note
                                        When using the 2.2-MHz setting, ensure that the input voltage and
                                        output voltage do not violate the minimum on-time in the device data
                                        sheet.

 JP3 – PG Pullup Voltage          PG pin pullup voltage jumper. Place the supplied jumper on JP3 to connect the
                                  PG pin pullup resistor to VOUT. Alternatively, the jumper can be removed and a
                                  different voltage can be supplied on pin 2 to pull up the PG pin to a different level.
                                  This externally applied voltage should remain below 18 V.

SLVUBX2B – AUGUST 2020 – REVISED MAY 2021                                 TPS6291x Step-Down Converter Evaluation Module User's Guide       5
Submit Document Feedback
                                            Copyright © 2021 Texas Instruments Incorporated

Setup                                                                                                                               www.ti.com

2.2 Ripple Measurement Setup
The extremely low noise and low ripple levels of the TPS6291x necessitate a low-noise test setup for accurately
measuring the output voltage ripple. The SMA connectors, J4 and J5, should be used to measure the output
voltage ripple, before and after the second LC filter. Do not use a normal 10x oscilloscope probe with a
high-impedance termination to the oscilloscope. Instead, connect the SMA connector directly to the oscilloscope
with a coaxial (coax) cable through a DC blocker. A DC blocker enables the use of the smallest V/div setting
on the oscilloscope to view the ripple. To prevent noise pickup and block reflections on the coax cable, the
oscilloscope should be set to full bandwidth (BW) and DC coupling with a 50-Ω termination.
Figure 2-1 and Figure 2-4 show the correct measurement settings and output voltage ripple result, while Figure
2-2, Figure 2-3, Figure 2-5, and Figure 2-6 show common measurement methods and settings that cannot
accurately measure the very low output voltage ripple. The measurements in Appendix A show the higher ripple
that results when the inductor is not installed in its low-noise orientation.

    VIN = 12 V, VOUT = 1.2 V, IOUT = 1000 mA, JP2 Open, Full BW, DC Coupling, 50-Ω Termination With DC Blocker

                                       Figure 2-1. Output Voltage Ripple, Measured at J4

    VIN = 12 V, VOUT = 1.2 V, IOUT = 1000 mA, JP2 Open, Full BW, DC Coupling, 50-Ω Termination With DC Blocker

                         Figure 2-2. Output Voltage Ripple, Measured across C4 With 1x Probe

6       TPS6291x Step-Down Converter Evaluation Module User's Guide                                  SLVUBX2B – AUGUST 2020 – REVISED MAY 2021
                                                                                                                       Submit Document Feedback
                                                   Copyright © 2021 Texas Instruments Incorporated

www.ti.com                                                                                                                                Setup

     VIN = 12 V, VOUT = 1.2 V, IOUT = 1000 mA, JP2 Open, Full BW, AC Coupling, High-Impedance Termination Without DC Blocker

                     Figure 2-3. Output Voltage Ripple, Measured Across C4 With 10x Probe

     VIN = 12 V, VOUT = 1.2 V, IOUT = 1000 mA, JP2 Open, Full BW, DC Coupling, 50-Ω Termination With DC Blocker

                                   Figure 2-4. Output Voltage Ripple, Measured at J5

SLVUBX2B – AUGUST 2020 – REVISED MAY 2021                                   TPS6291x Step-Down Converter Evaluation Module User's Guide       7
Submit Document Feedback
                                              Copyright © 2021 Texas Instruments Incorporated

Setup                                                                                                                               www.ti.com

    VIN = 12 V, VOUT = 1.2 V, IOUT = 1000 mA, JP2 Open, Full BW, DC Coupling, 50-Ω Termination With DC Blocker

                         Figure 2-5. Output Voltage Ripple, Measured Across C7 With 1x Probe

    VIN = 12 V, VOUT = 1.2 V, IOUT = 1000 mA, JP2 Open, Full BW, AC Coupling, High-impedance Termination Without DC Blocker

                        Figure 2-6. Output Voltage Ripple, Measured Across C7 With 10x Probe

8       TPS6291x Step-Down Converter Evaluation Module User's Guide                                  SLVUBX2B – AUGUST 2020 – REVISED MAY 2021
                                                                                                                       Submit Document Feedback
                                                   Copyright © 2021 Texas Instruments Incorporated

www.ti.com                                                                                                                         Test Results

3 Test Results
The TPS6291xEVM-077 was used to take all the data in the TPS6291x data sheet. See the device data sheet
for the performance of this EVM.
Figure 3-1 shows the thermal performance of the EVM. "Spot" shows the temperature of the PCB. Figure 3-2
shows the loop response measurement.

             Figure 3-1. Thermal Performance (VIN = 12 V, VOUT = 1.2 V, IOUT = 3000 mA, JP2 Open)
                                         90                                                              180
                                                                                             Gain (dB)
                                         70                                                  Phase (deg) 140
                                         50                                                                100

                                         30                                                                60
                             Gain (dB)

                                         10                                                                20

                                         -10                                                               -20

                                         -30                                                               -60

                                         -50                                                               -100

                                         -70                                                               -140

                                         -90                                                             -180
                                           100        1000           10000             100000        1000000
                                                                 Frequency (Hz)                          D001

        Figure 3-2. Loop Response Measurement (VIN = 12 V, VOUT = 1.2 V, IOUT = 3000 mA, JP2 open)

SLVUBX2B – AUGUST 2020 – REVISED MAY 2021                                      TPS6291x Step-Down Converter Evaluation Module User's Guide    9
Submit Document Feedback
                                                 Copyright © 2021 Texas Instruments Incorporated

Board Layout                                                                                                                     www.ti.com

4 Board Layout
This section provides the EVM board layout and illustrations in Figure 4-1 through Figure 4-6. The Gerbers are
available on the EVM product page. Revision B of the PCB just added a pin 1 indicator for the inductor, in the
silkscreen, to ensure that the inductor is assembled with the lowest-noise polarity.

                                                     Figure 4-1. Top Assembly

                                                        Figure 4-2. Top Layer

10   TPS6291x Step-Down Converter Evaluation Module User's Guide                                  SLVUBX2B – AUGUST 2020 – REVISED MAY 2021
                                                                                                                    Submit Document Feedback
                                                Copyright © 2021 Texas Instruments Incorporated

www.ti.com                                                                                                                   Board Layout

                                                Figure 4-3. Internal Layer 1

                                                Figure 4-4. Internal Layer 2

SLVUBX2B – AUGUST 2020 – REVISED MAY 2021                                 TPS6291x Step-Down Converter Evaluation Module User's Guide   11
Submit Document Feedback
                                            Copyright © 2021 Texas Instruments Incorporated

Board Layout                                                                                                                     www.ti.com

                                                     Figure 4-5. Bottom Layer

                                              Figure 4-6. Bottom Layer (Mirrored)

12   TPS6291x Step-Down Converter Evaluation Module User's Guide                                  SLVUBX2B – AUGUST 2020 – REVISED MAY 2021
                                                                                                                    Submit Document Feedback
                                                Copyright © 2021 Texas Instruments Incorporated

www.ti.com                                                                                                                                                                                                                                    Schematic and Bill of Materials

5 Schematic and Bill of Materials
This section provides the EVM schematic and bill of materials (BOM).
5.1 Schematic
Figure 5-1 and Figure 5-2 illustrate the EVM schematics.
                                                                                                                                                                                                        VOUT                                               VOUT_FILT
                                                                                                                                                                                                         J4                                                        J5
                                                                                                                                                                                                  2                                                        2
                                                                                                                                                                                                  3                                                        3
                                                                                                                                                                                                  4                                                        4
                                                                                                                                                                                                  5                                                        5

                                                                                                                                                                                                        1

                                                                                                                                                                                                                                                                   1
                                                                                                                                                                                           GND                                                    GND

                                                                                                                                                                                                 C11                                                                           C12
                                                                                                                                              SW                                                470pF                                                                         470pF
                                                                                                                                              TP1
                                                                                                            U1
             J1                                                                                                                                                                            GND                                                                          GND                                               J2
                                                                                                                                                    L1
                   1                 VIN                                                               6                           2   SW                                                                                                                                             VOUT_FILT                       1
       VIN                                                                                                  VIN              SW
                   2                                                                                                                                                                                                                                                                                                  2        VOUT_FILT
3V to 17V                                                                                                                                           2.2µH                                                                               FB1
                   3                                                                           EN       1                          3   VOUT                                                                                                                                                                           3
        S+                                                                                                  EN/SYNC          VO                                                                                                                                                                                                S+
                   4                          C10    C14    C3     C2                                                                                                                                                                                                                                                 4
        S-                                                                 C1                                                                                                                             C4     C5     C6     C15    C16         C7        C8                C17       C18        C19                         S-
                   5                                 10uF   10uF   10uF                        SCONF   10                          9   FB                                      R8   VOUT_FILT                                                                                                                         5
                                              47uF                                                          S-CONF           FB
     GND           6                                 25V    25V    25V    2200pF                                                                                                                         22uF   22uF   22uF   22uF   2200pF      22uF      22uF              22uF      22uF       2200pF              6        GND
                                                                                                       7                           8   SS                                      0
                                                                                                            PSNS           NR/SS
                                                                                                                                                                           R5
                                                                                                                                   5   PG                                  49.9
                                                                                                                             PG

                               GND                                                                                                 4
                                                                                                                           PGND
                                                                                                            TPS62913RPUR                                                   R1         C13
                                                                                                                                                            C9
                                                                                                                                                                           2.43k      100nF                                                                                                               GND
                                                                                                                                                            0.47µF

                                                                                         GND                                           GND
                                                                                                                                                                           R2
                                                                                                                                                                           4.87k
                                                                                                                                                                                                                                               VOUT_FILT
                                                                                                                                                                                                                                                                       JP3
                                                                                                                                                                                                                                                               1
                                                                                                                                                                                                                                                               2
             JP1                       R6
                   1   VIN                                                                                                                                               GND
      ON                              1.00M
                   2
EN/SYNC
                   3                 R7                                                                                                                                                                                                                    R3
     OFF
                                 1.00M                                                                                                                                                                                                                     10.0k
                                                                                                                                                                                                                                                                                                           J3
                       GND                                                                                                                                                                                                                                                                            1
                                                                                                                                                                                                                                                                                                                PG
                                                                                                                                                                                                                                                                                                      2
                                                                                                                                                                                                                                                                                                                GND
             JP2
                   1     VIN
 2.2 MHz
                   2
 S-CONF
                   3
   1 MHz

                                                                                     R4
                                                                                     52.3k
                       GND

                                                                                   GND

                                                                                               Figure 5-1. TPS62913EVM-077 Schematic
                                                                                                                                                                                                        VOUT                                               VOUT_FILT
                                                                                                                                                                                                         J4                                                        J5
                                                                                                                                                                                                  2                                                        2
                                                                                                                                                                                                  3                                                        3
                                                                                                                                                                                                  4                                                        4
                                                                                                                                                                                                  5     1                                                  5

                                                                                                                                                                                                                                                                   1
                                                                                                                                                                                           GND                                                    GND

                                                                                                                                                                                                 C11                                                                           C12
                                                                                                                                              SW                                                470pF                                                                         470pF
                                                                                                                                              TP1
                                                                                                            U1
             J1                                                                                                                                                                            GND                                                                          GND                                               J2
                                                                                                                                                    L1
                   1                 VIN                                                               6                           2   SW                                                                                                                                             VOUT_FILT                       1
       VIN                                                                                                  VIN              SW
                   2                                                                                                                                                                                                                                                                                                  2        VOUT_FILT
3V to 17V                                                                                                                                           2.2µH                                                                               FB1
                   3                                                                           EN       1                          3   VOUT                                                                                                                                                                           3
        S+                                                                                                  EN/SYNC          VO                                                                                                                                                                                                S+
                   4                          C10    C14    C3     C2                                                                                                                                                                                                                                                 4
        S-                                                                 C1                                                                                                                             C4     C5     C6     C15    C16         C7        C8                C17       C18        C19                         S-
                   5                                 10uF   10uF   10uF                        SCONF   10                          9   FB                                      R8   VOUT_FILT                                                                                                                         5
                                              47uF                                                          S-CONF           FB
     GND           6                                 25V    25V    25V    2200pF                                                                                                                         22uF   22uF   22uF   22uF   2200pF      22uF      22uF              22uF      22uF       2200pF              6        GND
                                                                                                       7                           8   SS                                      0
                                                                                                            PSNS           NR/SS
                                                                                                                                                                           R5
                                                                                                                                   5   PG                                  49.9
                                                                                                                             PG

                               GND                                                                                                 4
                                                                                                                           PGND
                                                                                                            TPS62912RPUR                                                   R1         C13
                                                                                                                                                            C9             15.4k      100nF                                                                                                               GND
                                                                                                                                                            0.47µF

                                                                                         GND                                           GND
                                                                                                                                                                           R2
                                                                                                                                                                           4.87k
                                                                                                                                                                                                                                               VOUT_FILT
                                                                                                                                                                                                                                                                       JP3
                                                                                                                                                                                                                                                               1
                                                                                                                                                                                                                                                               2
             JP1                       R6
                   1   VIN                                                                                                                                               GND
      ON                              1.00M
                   2
EN/SYNC
                   3                 R7                                                                                                                                                                                                                    R3
     OFF
                                 1.00M                                                                                                                                                                                                                     10.0k
                                                                                                                                                                                                                                                                                                           J3
                       GND                                                                                                                                                                                                                                                                            1
                                                                                                                                                                                                                                                                                                                PG
                                                                                                                                                                                                                                                                                                      2
                                                                                                                                                                                                                                                                                                                GND
             JP2
                   1     VIN
 2.2 MHz
                   2
 S-CONF
                   3
   1 MHz

                                                                                     R4
                                                                                     27.4k
                       GND

                                                                                   GND

                                                                                               Figure 5-2. TPS62912EVM-077 Schematic

SLVUBX2B – AUGUST 2020 – REVISED MAY 2021                                                                                                                            TPS6291x Step-Down Converter Evaluation Module User's Guide                                                                                                     13
Submit Document Feedback
                                                                                                            Copyright © 2021 Texas Instruments Incorporated

Bill of Materials                                                                                                                                                                 www.ti.com

6 Bill of Materials
Table 6-1 lists the BOM for this EVM.

                                                                      Table 6-1. TPS6291xEVM-077 Bill of Materials
                               Reference
     -002        -003                                  Value         Description                                                 Package    Part Number            Manufacturer
                               Designator

      1             1               C1                2200pF         CAP, CERM, 2200 pF, 50 V, +/- 10%, X7R                      0402       GRM155R71H222KA01D     muRata

      2             2             C2, C3                10µF         CAP, CERM, 10µF, 25 V, +/- 10%, X7S                         0805       C2012X7S1E106K125AC TDK

      5             5      C4, C5, C6, C7, C8           22µF         CAP, CERM, 22 µF, 10 V, +/- 20%, X7S                        0805       C2012X7S1A226M125AC TDK

      1             1               C9                 0.47µF        CAP, CERM, 0.47 µF, 25 V, +/- 10%, X7R                      0603       C1608X7R1E474K080AE TDK

      1             1              C10                  47µF         CAP, TA, 47 µF, 35 V, +/- 10%, 0.3 Ω                        7343-43    T495X476K035ATE300     Kemet

      2             2           C11, C12               470pF         CAP, CERM, 470 pF, 50 V, +/- 5%, C0G/NP0                    0402       GRM1555C1H471JA01D     muRata

      1             1              FB1                               Ferrite bead, 8.5-Ω at 100 MHz, 4mΩ DCR, 8A                 0603       BLE18PS080SN1          muRata

      1             1               L1                 2.2µH         Inductor Power Shielded Wirewound 2.2µH 20%                 4 x 4 mm   XGL4030-222MEC         Coilcraft
                                                                     Composite 8.7A 13.5mΩ DCR

      0             1               R1                 2.43kΩ        RES, 2.43 kΩ, 1%, 0.1 W                                     0603       Std                    Std

      1             0               R1                 15.4kΩ        RES, 15.4 kΩ, 1%, 0.1 W                                     0603       Std                    Std

      1             1               R2                 4.87kΩ        RES, 4.87 kΩ, 1%, 0.1 W                                     0603       Std                    Std

      1             1               R3                 10.0kΩ        RES, 10.0 kΩ, 1%, 0.1 W                                     0603       Std                    Std

      1             0               R4                 27.4kΩ        RES, 27.4 kΩ, 1%, 0.1 W                                     0603       Std                    Std

      0             1               R4                 52.3kΩ        RES, 52.3 kΩ, 1%, 0.1 W                                     0603       Std                    Std

      1             0               U1              TPS629121        3V to 17V, 2A Low Noise (20 µVRMS) and Low Ripple 2 x 2 mm             TPS62912RPUR           Texas Instruments
                                                                     (200 µVPP) buck converter

      0             1               U1              TPS629131        3V to 17V, 3A Low Noise (20 µVRMS) and Low Ripple 2 x 2 mm             TPS62913RPUR           Texas Instruments
                                                                     (200 µVPP) buck converter

1. The TPS6291xEVM-077 may be populated with TPS6291x (U1) devices that do not contain the correct top-side markings on the top of the device
   itself. These devices are still fully-tested TPS6291x devices.

14          TPS6291x Step-Down Converter Evaluation Module User's Guide                                                                            SLVUBX2B – AUGUST 2020 – REVISED MAY 2021
                                                                                                                                                                     Submit Document Feedback
                                                                               Copyright © 2021 Texas Instruments Incorporated

www.ti.com                                                                               Ripple Measurements With Mis-oriented Inductor

A Ripple Measurements With Mis-oriented Inductor
This section shows the output ripple measurement results when the inductor is not installed in its low-noise
orientation. This was the case on the Revision A EVMs.

     VIN = 12 V, VOUT = 1.2 V, IOUT = 1000 mA, JP2 Open, Full BW, DC Coupling, 50-Ω Termination With DC Blocker

                                   Figure A-1. Output Voltage Ripple, Measured at J4

     VIN = 12 V, VOUT = 1.2 V, IOUT = 1000 mA, JP2 Open, Full BW, DC Coupling, 50-Ω Termination With DC Blocker

                      Figure A-2. Output Voltage Ripple, Measured across C4 With 1x Probe

SLVUBX2B – AUGUST 2020 – REVISED MAY 2021                                   TPS6291x Step-Down Converter Evaluation Module User's Guide   15
Submit Document Feedback
                                              Copyright © 2021 Texas Instruments Incorporated

Ripple Measurements With Mis-oriented Inductor                                                                                    www.ti.com

     VIN = 12 V, VOUT = 1.2 V, IOUT = 1000 mA, JP2 Open, Full BW, AC Coupling, High-Impedance Termination Without DC Blocker

                      Figure A-3. Output Voltage Ripple, Measured Across C4 With 10x Probe

     VIN = 12 V, VOUT = 1.2 V, IOUT = 1000 mA, JP2 Open, Full BW, DC Coupling, 50-Ω Termination With DC Blocker

                                     Figure A-4. Output Voltage Ripple, Measured at J5

16    TPS6291x Step-Down Converter Evaluation Module User's Guide                                  SLVUBX2B – AUGUST 2020 – REVISED MAY 2021
                                                                                                                     Submit Document Feedback
                                                 Copyright © 2021 Texas Instruments Incorporated

www.ti.com                                                                                                                                     Revision History

     VIN = 12 V, VOUT = 1.2 V, IOUT = 1000 mA, JP2 Open, Full BW, DC Coupling, 50-Ω Termination With DC Blocker

                          Figure A-5. Output Voltage Ripple, Measured Across C7 With 1x Probe

     VIN = 12 V, VOUT = 1.2 V, IOUT = 1000 mA, JP2 Open, Full BW, AC Coupling, High-impedance Termination Without DC Blocker

                         Figure A-6. Output Voltage Ripple, Measured Across C7 With 10x Probe

Revision History
NOTE: Page numbers for previous revisions may differ from page numbers in the current version.
Changes from Revision A (March 2021) to Revision B (May 2021)                                                                                            Page
• Updated user's guide title................................................................................................................................... 2
• Updated the numbering format for tables, figures, and cross-references throughout the document. ................2

Changes from Revision * (August 2020) to Revision A (March 2021)                                                                Page
• Updated all images in the Ripple Measurement Setup section.......................................................................... 6
• Moved original Ripple Measurement Setup section to Appendix..................................................................... 15

SLVUBX2B – AUGUST 2020 – REVISED MAY 2021                                              TPS6291x Step-Down Converter Evaluation Module User's Guide             17
Submit Document Feedback
                                                       Copyright © 2021 Texas Instruments Incorporated

                                       IMPORTANT NOTICE AND DISCLAIMER
TI PROVIDES TECHNICAL AND RELIABILITY DATA (INCLUDING DATA SHEETS), DESIGN RESOURCES (INCLUDING REFERENCE
DESIGNS), APPLICATION OR OTHER DESIGN ADVICE, WEB TOOLS, SAFETY INFORMATION, AND OTHER RESOURCES “AS IS”
AND WITH ALL FAULTS, AND DISCLAIMS ALL WARRANTIES, EXPRESS AND IMPLIED, INCLUDING WITHOUT LIMITATION ANY
IMPLIED WARRANTIES OF MERCHANTABILITY, FITNESS FOR A PARTICULAR PURPOSE OR NON-INFRINGEMENT OF THIRD
PARTY INTELLECTUAL PROPERTY RIGHTS.
These resources are intended for skilled developers designing with TI products. You are solely responsible for (1) selecting the appropriate
TI products for your application, (2) designing, validating and testing your application, and (3) ensuring your application meets applicable
standards, and any other safety, security, regulatory or other requirements.
These resources are subject to change without notice. TI grants you permission to use these resources only for development of an
application that uses the TI products described in the resource. Other reproduction and display of these resources is prohibited. No license
is granted to any other TI intellectual property right or to any third party intellectual property right. TI disclaims responsibility for, and you
will fully indemnify TI and its representatives against, any claims, damages, costs, losses, and liabilities arising out of your use of these
resources.
TI’s products are provided subject to TI’s Terms of Sale or other applicable terms available either on ti.com or provided in conjunction with
such TI products. TI’s provision of these resources does not expand or otherwise alter TI’s applicable warranties or warranty disclaimers for
TI products.
TI objects to and rejects any additional or different terms you may have proposed. IMPORTANT NOTICE

                             Mailing Address: Texas Instruments, Post Office Box 655303, Dallas, Texas 75265
                                            Copyright © 2022, Texas Instruments Incorporated

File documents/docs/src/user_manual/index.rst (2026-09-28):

User Manual
===========

The manual will be a concise instrument reference, similar in scope to the
manuals supplied with commercial digital delay and pulse generators. It will
cover system and channel parameters, their meanings and limits, timing modes,
triggering, gating, and everyday device operation.

It will be authored in LaTeX and distributed as a printable PDF. This page is
reserved for that document; the manual is separate from the detailed
:doc:`User Guide <../users_guide/index>`, :doc:`API Reference
<../api_reference/index>`, and experimental case studies.

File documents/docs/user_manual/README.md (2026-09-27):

# User manual PDF

Place holder until I have time to make the PDF and latex stuff.

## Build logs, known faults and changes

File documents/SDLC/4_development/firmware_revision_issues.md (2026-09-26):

# Development Issues for the OpenSync Firmware

## Version History
| Date | Version | Change | 
| --- | --- | --- |
| 09/20/2026 | 0.1.0 | Intitial publishment. |

## Key Words
- DMA - Direct Memory Access
- FIFO - First in, First out
- RXFIFO - Receive First In, First Out
- TXFIFO - Transmit First In, First Out
- ISR - Input Shift Register
- OSR - Output Shift Register
- PIO - Programmable Input/Output
- GPIO - General Purpose Input/Output
- Word - A 32 bit variable in assembly language

## 1. Introduction
An updated version of the OpenSync synchronizer inspired from commercial digital delay/pulse generators is currently under development. This new revision places a focus on truely independent and programmable output channels using microcontroller technology. Each output channel consists of four counters (wait counter, burst counter, pulse counter, off counter) and an instruction buffer. Additionally, a gate selector allows for each channel to be configured for pulse or output inhibit. This effectively allowed for a wide variety of pulse sequences to be programmed. For instance, a wait counter allows for a select number of events to be ignored before starting pulse sequences. Burst counters work in the opposite way by limiting the number of pulses a channel may perform before it is disabled. Finally, pulse and off counters allow for instruction buffers to be executed in a determinate pattern based on internal or external events.

The core implementation details of the programs have been detailed a few times already in the previous sections, so beyond the brief overview given above, the overall design would not be repreated. However, the design of the PIO programs and state machine configuration functions would be discussed in short. The basic idea is a PIO program that consumes a ring buffer that hold the pulse sequencer's instructions. In addition to the ring buffer, there are RXFIFO memory slots used to store the counters and gate selection. The RXFIFO memory slots are populated by the state machine helper functions which convert the SCPI interface configs into usable instructions. Then, a DMA ring buffer is constructed and loaded to prevent memory stalls which could derail program oepration. Conceptually, the work flow can be visualized using the below generated image since it is hard to explain the inner workings of a constantly changing firmware. 

Figure 1. Highest Level PCB Schematic
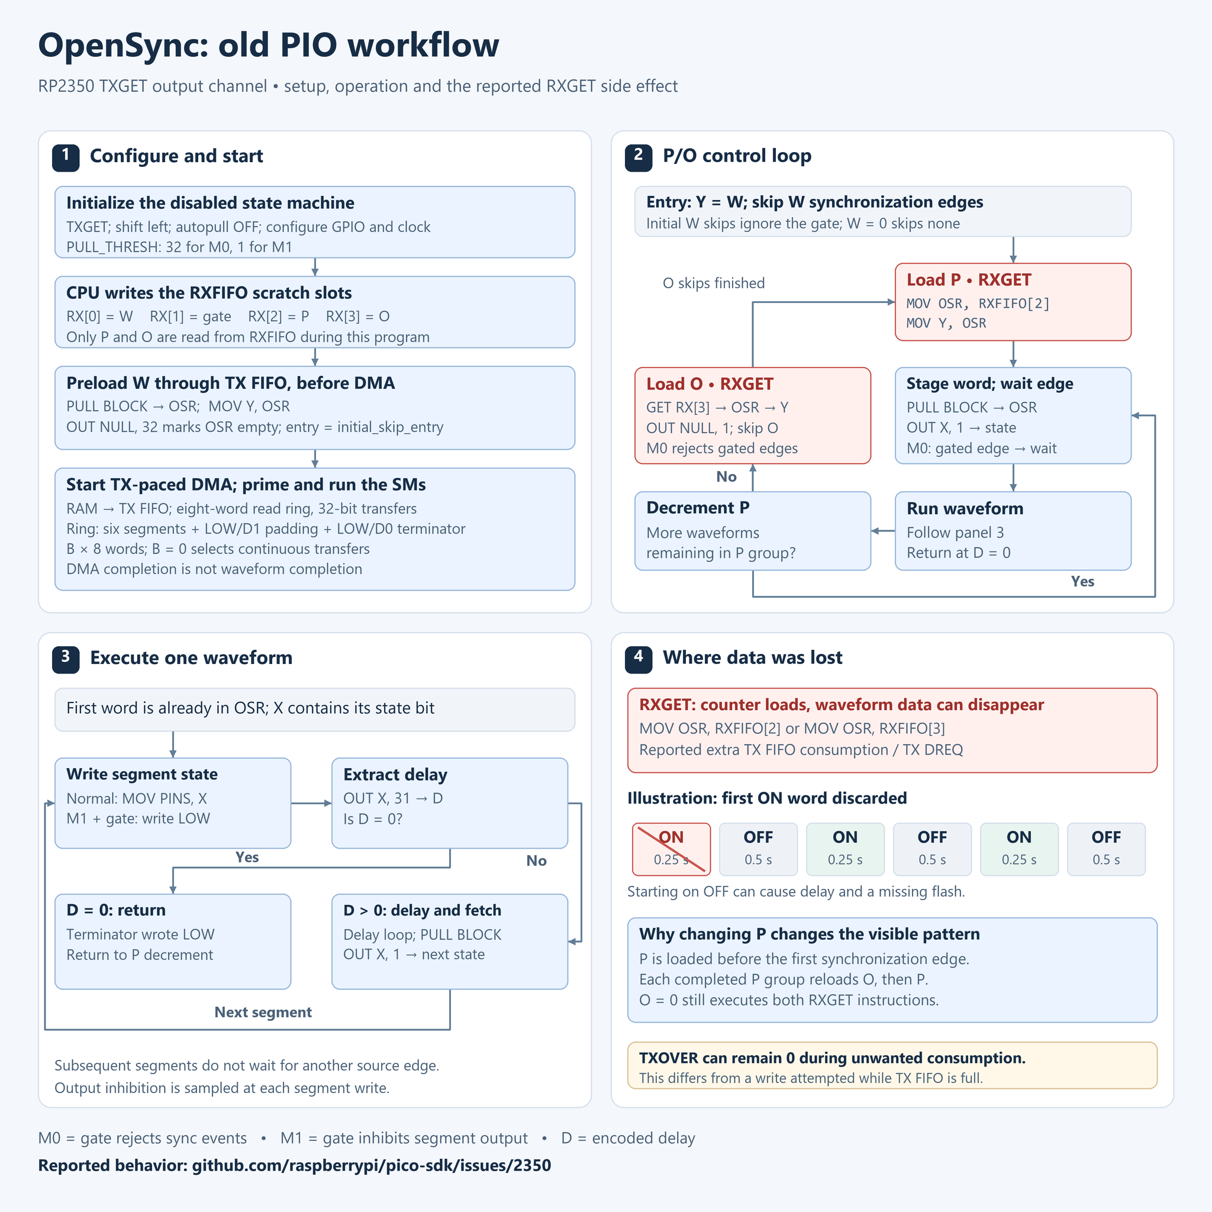
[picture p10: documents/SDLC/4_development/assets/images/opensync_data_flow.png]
Data Flow Diagram


## 2. Technical DIfficulties
During development, an interesting issue occured when testing the updated firmware. When programming the firmware using the instructions seen in Appendix A, an unexpected observation would occur. When triggering the external trigger, it was expected that three sets of three pulses would be produced. However, a noticable delay between the trigger and the first LED connected to the synchronizer occured along with missing pulses. This peculiar issue befuddled the author for a few hours. Even worse, sometimes no pulses would even emit out of the synchronizer once armed and triggered. This extraordinarily recalcitrant, capricious, and exasperating anomaly finaly had some resemblance of comprehension after reading a GitHub issue on Raspberry Pi Foundation's pico-sdk repository. This issue, [linked here](https://github.com/raspberrypi/pico-sdk/issues/2350) mentioned that when using rxfifo in conjunction with DMA channels, information can become lost when accessing rxfifo memory. This is due to a wierd behavior where pulling rxfifo memory into OSR also pulls the next word from the DMA channel which is subsequently discarded. In principal, it appears that for every rxfifo memory access that occurs, it overwrites one word from the DMA's FIFO buffer causing the delay and erratic behavior seen in the OpenSync device. After further debug statements, issues where no pulsing even occurs were noted to have TXFIFO overflow which doomed the program operation to an unholy level of computational damnation and peripheral-based indignity. Further issues in unpredictable pulsing was found to be caused by the overwriting of DMA pulse instructions.

## 3. Solutions to the Problem
After much contemplatation, the usage of RXFIFO in the pulse sequencer PIO programs were scrubbed for eternity. Instead, a modified version of the original firmware (OpenSync's arbitrary pulse generator prototype) was used in conjunction with the duty cycle-based program operation. This removal of the RXFIFO memory from the program minimized any noticable delays and the synchronizer appears to operate as intended. All instructions executed without data loss from RXFIFO memory access pulling and overwriting memory from the FIFO buffer.

## Appendix A. OpenSync Configuration During Testing
pulse0:state on

pulse0:divider 1

pulse0:period 3 s

pulse0:bcounter 1

pulse0:pcounter 3

pulse0:ocounter 0

pulse0:trigger:mode triggered

pulse0:trigger:edge rising

pulse0:gate:mode disabled

pulse1:state on

pulse1:divider 1

pulse1:buffer on, 0.25 s, off, 0.5 s, on, 0.25 s, off, 0.5 s, on, 0.25 s, off, 0.5 s

pulse1:sync t0

pulse1:bcounter 0

pulse1:pcounter 1

pulse1:ocounter 0

pulse2:state on

pulse2:divider 1

pulse2:buffer off, 0.25 s, on, 0.5 s, off, 0.25 s, on, 0.5 s, off, 0.25 s, on, 0.5 s

pulse2:sync t0

pulse2:bcounter 0

pulse2:pcounter 1

pulse2:ocounter 0

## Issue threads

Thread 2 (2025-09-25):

Main PLL Clock Speed

ErichZimmer, 2025-09-25:
## Context
The main PLL clock speed dictates how quickly instructions are executed. The RP2350 microcontroller can operate at >400 MHz with fine-tuning of the PLL clock dividers. Without modifying these PLL clock dividers, the system is limited to <288 MHz since peripherals tend to fail due to overclocking.

## Solutions
 - Overclock to 200 MHz
Overlocking to 200 MHz gives a resolution of 5 ns, which is often enough since the rise and fall times of the 3v to 5v TTL logic transceivers are 4 ns. At 200 MHz, all peripherals still work.

 - Overclock to 250 MHz
 Overclocking to 250 MHz gives a resolution of 4 ns. All else is equal in comparison to overclocking to 200 MHz (e.g., all peripherals still work)

- Overclock to 300 MHz
Overclocking to 300 MHz gives a resolution of ~3.3 ns and requires the modification of PLL dividers to make sure all peripherals are still functioning as intended. Most, if not all, RP2350 microcontrollers can be overclocked to this clock speed (even slow dies).

- Overclock to 336 MHz
-Overclocking to 336 MHz gives a resolution of ~3 ns and requires the modification of PLL dividers to make sure everything works. The transceivers used in the PCB has a rise/fall time of 4 ns, so it may not make sense to overclock this much.

ErichZimmer, 2025-10-01:
I went with 250 MHz due to presumed stability and the lack of necessity for modifying PLL dividers. A 4 ns resolution seems good enough as that is around the same as Dantec Dynamic's synchronizers. Jitter can be minimized with extra ICs or TDC (time to delay converters) which would allow for sub ns jitter.

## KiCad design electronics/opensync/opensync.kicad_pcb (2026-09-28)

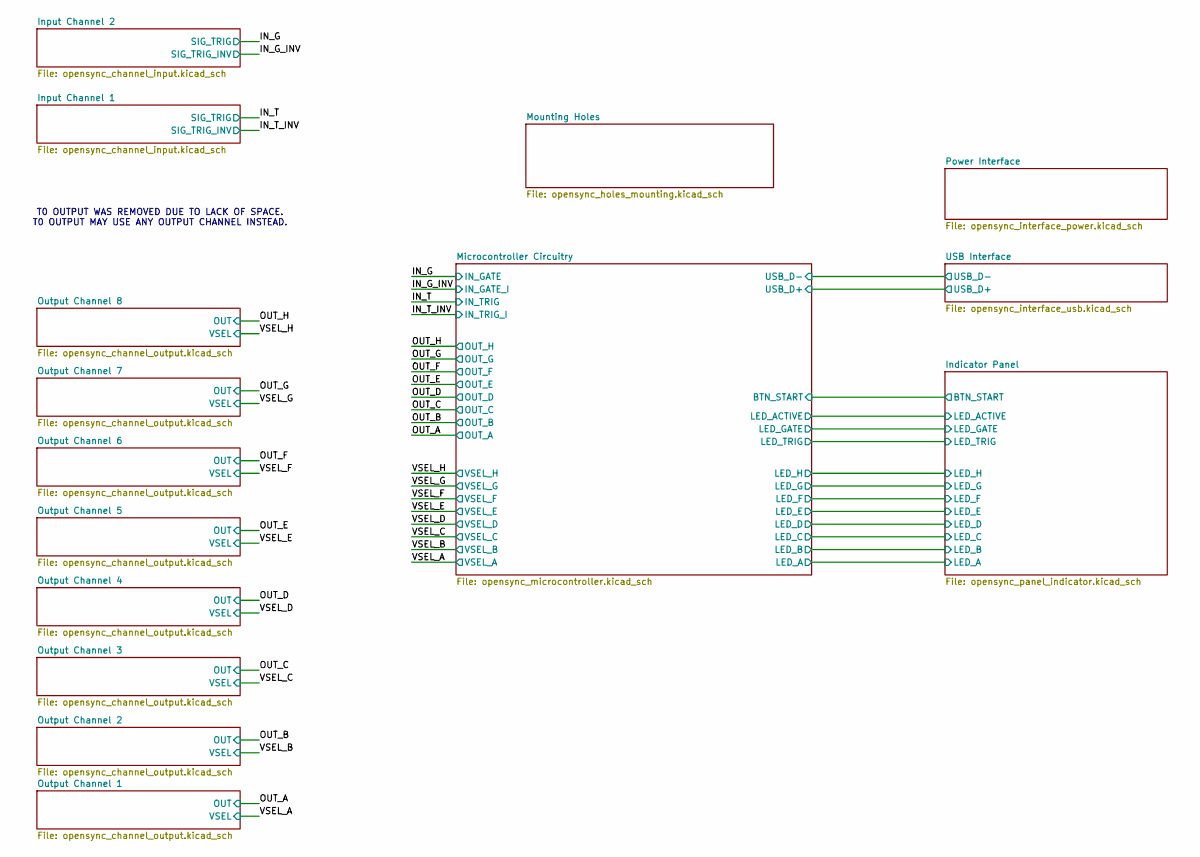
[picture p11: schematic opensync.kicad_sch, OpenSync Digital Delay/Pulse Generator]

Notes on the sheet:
T0 OUTPUT WAS REMOVED DUE TO LACK OF SPACE. T0 OUTPUT MAY USE ANY OUTPUT CHANNEL INSTEAD.

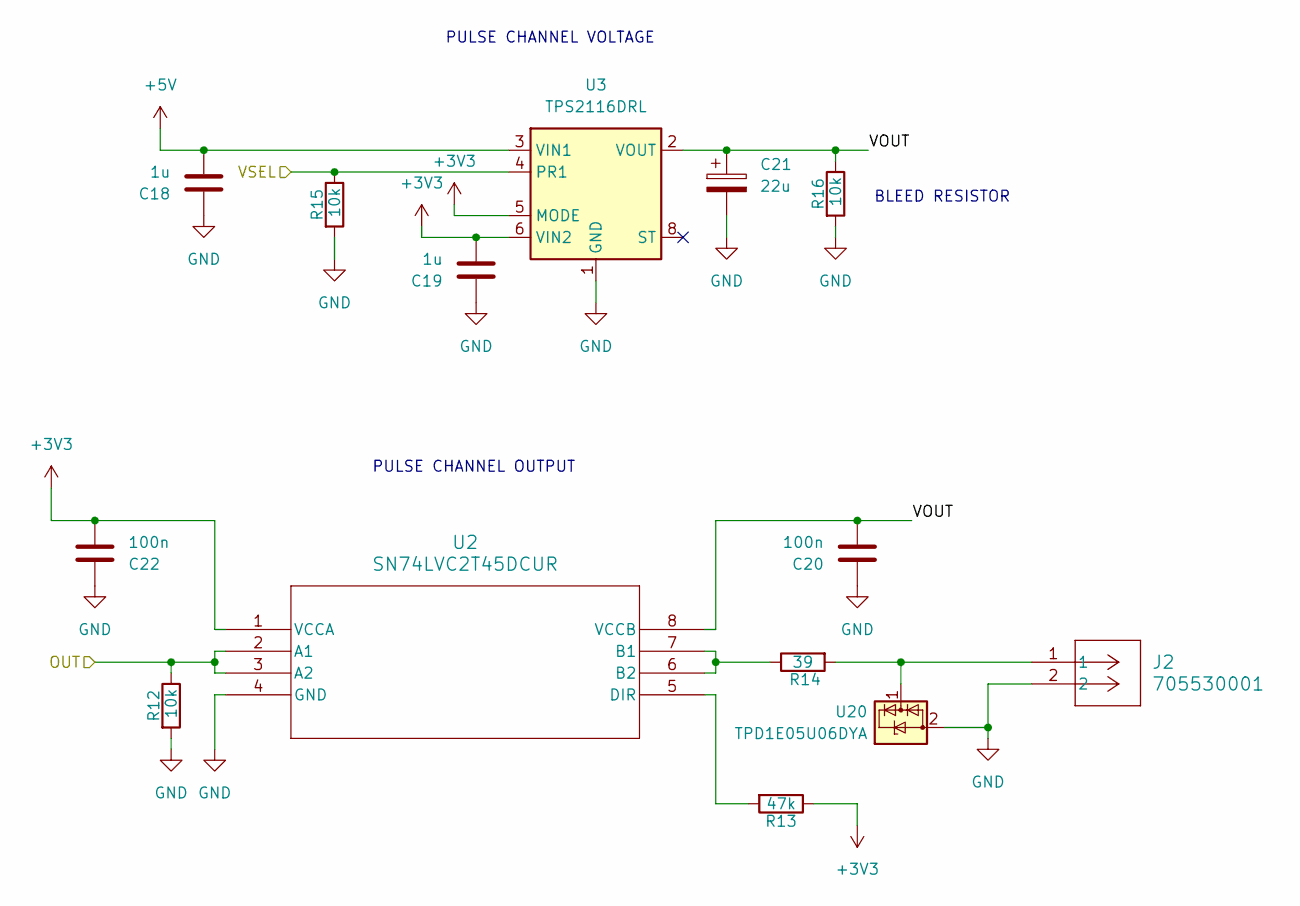
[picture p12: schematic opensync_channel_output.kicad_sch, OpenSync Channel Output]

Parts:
C18, C19: 1u; C_0603_1608Metric; voltage 25V; tolerance ±10%; manufacturer_pn CGA3E1X7R1E105KT0Y0E; LCSC C76708
C20, C22: 100n; C_0402_1005Metric_small_pads; voltage 50V; tolerance ±10%; manufacturer_pn CGA2B3X7R1H104KT0Y0F; LCSC C343042
C21: 22u; CP_Elec_4x5.4; voltage 10V; tolerance ±20%; manufacturer_pn 865060240001; LCSC C2164097
J2: 705530001; CONN_705530001_02_MOL
R12, R15: 10k; R_0402_1005Metric; tolerance ±1%; voltage 50V; manufacturer_pn CRCW040210K0FKED; LCSC C71617
R13: 47k; R_0402_1005Metric; tolerance ±1%; voltage 50V; manufacturer_pn CRCW040247K0FKED; LCSC C482184
R14: 39; R_0603_1608Metric; tolerance ±1%; voltage 75V; manufacturer_pn RCS060339R0FKEA; LCSC C2105598
R16: 10k; R_0603_1608Metric; tolerance ±1%; voltage 75V; manufacturer_pn CRCW060310K0FKEA; LCSC C844918
U2: SN74LVC2T45DCUR; DCU8; voltage 1.65V~5.5V; manufacturer_pn SN74LVC2T45DCUR; LCSC C15741
U3: TPS2116DRL; SOT-583-8; manufacturer_pn TPS2116DRLR; LCSC C3235557
U20: TPD1E05U06DYA; D_SOD-523; manufacturer_pn TPD1E05U06DYAR; LCSC C3702980

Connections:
+3V3: C19.2, C22.2, R13.1, U2.1 (VCCA), U3.5 (MODE), U3.6 (VIN2); also elsewhere on the board
+5V: C18.2, U3.3 (VIN1); also elsewhere on the board
/OUT_A: R12.1, U2.2 (A1), U2.3 (A2); also elsewhere on the board
/Output Channel 1/VOUT: C20.2, C21.1, R16.1, U2.8 (VCCB), U3.2 (VOUT), U3.7 (VOUT)
/VSEL_A: R15.1, U3.4 (PR1); also elsewhere on the board
GND: C18.1, C19.1, C20.1, C21.2, C22.1, J2.2, R12.2, R15.2, R16.2, U2.4 (GND), U3.1 (GND), U20.2 (GND); also elsewhere on the board
unnamed: R14.1, U2.6 (B2), U2.7 (B1)
unnamed: R13.2, U2.5 (DIR)
unnamed: J2.1, R14.2, U20.1 (I/O)

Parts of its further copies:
C23, C24, C28, C29, C33, C34, C38, C39, C43, C44, C48, C49, C53, C54: 1u; C_0603_1608Metric; voltage 25V; tolerance ±10%; manufacturer_pn CGA3E1X7R1E105KT0Y0E; LCSC C76708
C25, C27, C30, C32, C35, C37, C40, C42, C45, C47, C50, C52, C55, C57: 100n; C_0402_1005Metric_small_pads; voltage 50V; tolerance ±10%; manufacturer_pn CGA2B3X7R1H104KT0Y0F; LCSC C343042
C26, C31, C36, C41, C46, C51, C56: 22u; CP_Elec_4x5.4; voltage 10V; tolerance ±20%; manufacturer_pn 865060240001; LCSC C2164097
J3, J4, J5, J6, J7, J8, J9: 705530001; CONN_705530001_02_MOL
R17, R20, R22, R25, R27, R30, R32, R35, R37, R40, R42, R45, R47, R50: 10k; R_0402_1005Metric; tolerance ±1%; voltage 50V; manufacturer_pn CRCW040210K0FKED; LCSC C71617
R18, R23, R28, R33, R38, R43, R48: 47k; R_0402_1005Metric; tolerance ±1%; voltage 50V; manufacturer_pn CRCW040247K0FKED; LCSC C482184
R19, R24, R29, R34, R39, R44, R49: 39; R_0603_1608Metric; tolerance ±1%; voltage 75V; manufacturer_pn RCS060339R0FKEA; LCSC C2105598
R21, R26, R31, R36, R41, R46, R51: 10k; R_0603_1608Metric; tolerance ±1%; voltage 75V; manufacturer_pn CRCW060310K0FKEA; LCSC C844918
U4, U6, U8, U10, U12, U14, U16: SN74LVC2T45DCUR; DCU8; voltage 1.65V~5.5V; manufacturer_pn SN74LVC2T45DCUR; LCSC C15741
U5, U7, U9, U11, U13, U15, U17: TPS2116DRL; SOT-583-8; manufacturer_pn TPS2116DRLR; LCSC C3235557
U21, U22, U23, U24, U25, U26, U27: TPD1E05U06DYA; D_SOD-523; manufacturer_pn TPD1E05U06DYAR; LCSC C3702980

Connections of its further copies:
+3V3: C24.2, C27.2, C29.2, C32.2, C34.2, C37.2, C39.2, C42.2, C44.2, C47.2, C49.2, C52.2, C54.2, C57.2, R18.1, R23.1, R28.1, R33.1, R38.1, R43.1, R48.1, U4.1 (VCCA), U5.5 (MODE), U5.6 (VIN2), U6.1 (VCCA), U7.5 (MODE), U7.6 (VIN2), U8.1 (VCCA), U9.5 (MODE), U9.6 (VIN2), U10.1 (VCCA), U11.5 (MODE), U11.6 (VIN2), U12.1 (VCCA), U13.5 (MODE), U13.6 (VIN2), U14.1 (VCCA), U15.5 (MODE), U15.6 (VIN2), U16.1 (VCCA), U17.5 (MODE), U17.6 (VIN2); also elsewhere on the board
+5V: C23.2, C28.2, C33.2, C38.2, C43.2, C48.2, C53.2, U5.3 (VIN1), U7.3 (VIN1), U9.3 (VIN1), U11.3 (VIN1), U13.3 (VIN1), U15.3 (VIN1), U17.3 (VIN1); also elsewhere on the board
/OUT_B: R17.1, U4.2 (A1), U4.3 (A2); also elsewhere on the board
/OUT_C: R22.1, U6.2 (A1), U6.3 (A2); also elsewhere on the board
/OUT_D: R27.1, U8.2 (A1), U8.3 (A2); also elsewhere on the board
/OUT_E: R32.1, U10.2 (A1), U10.3 (A2); also elsewhere on the board
/OUT_F: R37.1, U12.2 (A1), U12.3 (A2); also elsewhere on the board
/OUT_G: R42.1, U14.2 (A1), U14.3 (A2); also elsewhere on the board
/OUT_H: R47.1, U16.2 (A1), U16.3 (A2); also elsewhere on the board
/Output Channel 2/VOUT: C25.2, C26.1, R21.1, U4.8 (VCCB), U5.2 (VOUT), U5.7 (VOUT)
/Output Channel 3/VOUT: C30.2, C31.1, R26.1, U6.8 (VCCB), U7.2 (VOUT), U7.7 (VOUT)
/Output Channel 4/VOUT: C35.2, C36.1, R31.1, U8.8 (VCCB), U9.2 (VOUT), U9.7 (VOUT)
/Output Channel 5/VOUT: C40.2, C41.1, R36.1, U10.8 (VCCB), U11.2 (VOUT), U11.7 (VOUT)
/Output Channel 6/VOUT: C45.2, C46.1, R41.1, U12.8 (VCCB), U13.2 (VOUT), U13.7 (VOUT)
/Output Channel 7/VOUT: C50.2, C51.1, R46.1, U14.8 (VCCB), U15.2 (VOUT), U15.7 (VOUT)
/Output Channel 8/VOUT: C55.2, C56.1, R51.1, U16.8 (VCCB), U17.2 (VOUT), U17.7 (VOUT)
/VSEL_B: R20.1, U5.4 (PR1); also elsewhere on the board
/VSEL_C: R25.1, U7.4 (PR1); also elsewhere on the board
/VSEL_D: R30.1, U9.4 (PR1); also elsewhere on the board
/VSEL_E: R35.1, U11.4 (PR1); also elsewhere on the board
/VSEL_F: R40.1, U13.4 (PR1); also elsewhere on the board
/VSEL_G: R45.1, U15.4 (PR1); also elsewhere on the board
/VSEL_H: R50.1, U17.4 (PR1); also elsewhere on the board
GND: C23.1, C24.1, C25.1, C26.2, C27.1, C28.1, C29.1, C30.1, C31.2, C32.1, C33.1, C34.1, C35.1, C36.2, C37.1, C38.1, C39.1, C40.1, C41.2, C42.1, C43.1, C44.1, C45.1, C46.2, C47.1, C48.1, C49.1, C50.1, C51.2, C52.1, C53.1, C54.1, C55.1, C56.2, C57.1, J3.2, J4.2, J5.2, J6.2, J7.2, J8.2, J9.2, R17.2, R20.2, R21.2, R22.2, R25.2, R26.2, R27.2, R30.2, R31.2, R32.2, R35.2, R36.2, R37.2, R40.2, R41.2, R42.2, R45.2, R46.2, R47.2, R50.2, R51.2, U4.4 (GND), U5.1 (GND), U6.4 (GND), U7.1 (GND), U8.4 (GND), U9.1 (GND), U10.4 (GND), U11.1 (GND), U12.4 (GND), U13.1 (GND), U14.4 (GND), U15.1 (GND), U16.4 (GND), U17.1 (GND), U21.2 (GND), U22.2 (GND), U23.2 (GND), U24.2 (GND), U25.2 (GND), U26.2 (GND), U27.2 (GND); also elsewhere on the board
unnamed: R19.1, U4.6 (B2), U4.7 (B1)
unnamed: R18.2, U4.5 (DIR)
unnamed: R24.1, U6.6 (B2), U6.7 (B1)
unnamed: R23.2, U6.5 (DIR)
unnamed: R29.1, U8.6 (B2), U8.7 (B1)
unnamed: R28.2, U8.5 (DIR)
unnamed: R34.1, U10.6 (B2), U10.7 (B1)
unnamed: R33.2, U10.5 (DIR)
unnamed: R39.1, U12.6 (B2), U12.7 (B1)
unnamed: R38.2, U12.5 (DIR)
unnamed: R44.1, U14.6 (B2), U14.7 (B1)
unnamed: R43.2, U14.5 (DIR)
unnamed: R49.1, U16.6 (B2), U16.7 (B1)
unnamed: R48.2, U16.5 (DIR)
unnamed: J3.1, R19.2, U21.1 (I/O)
unnamed: J4.1, R24.2, U22.1 (I/O)
unnamed: J5.1, R29.2, U23.1 (I/O)
unnamed: J6.1, R34.2, U24.1 (I/O)
unnamed: J7.1, R39.2, U25.1 (I/O)
unnamed: J8.1, R44.2, U26.1 (I/O)
unnamed: J9.1, R49.2, U27.1 (I/O)

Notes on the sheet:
BLEED RESISTOR
PULSE CHANNEL OUTPUT
PULSE CHANNEL VOLTAGE

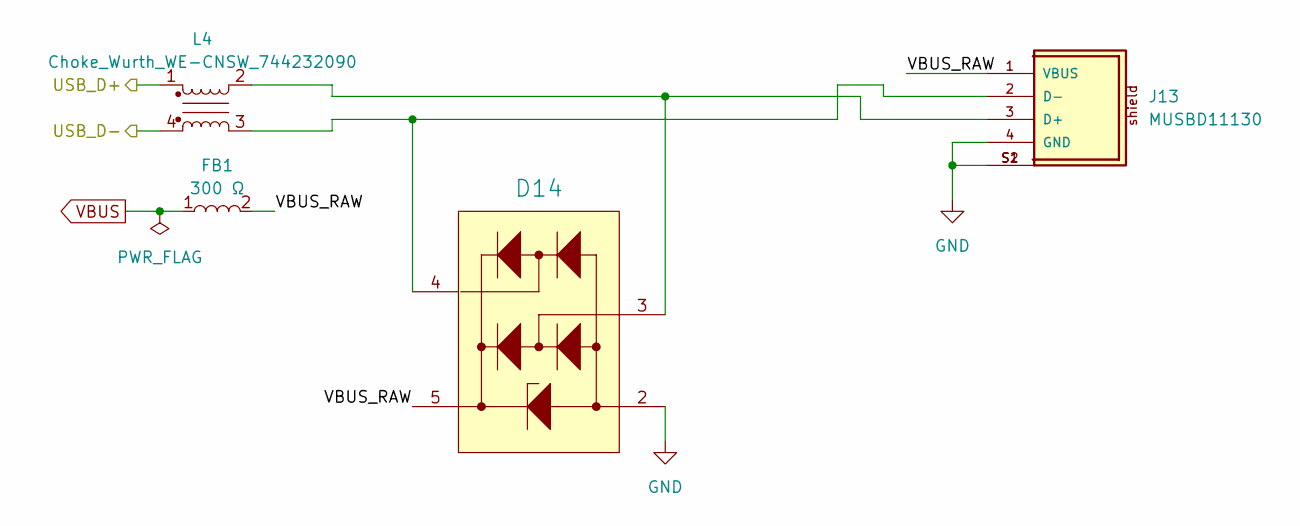
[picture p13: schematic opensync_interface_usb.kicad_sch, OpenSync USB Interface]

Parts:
D14: 5V; WE-TVS_SOT23-5L; Manufacturer Part Number 824011; LCSC C5341668
FB1: 0603_W2.6_742792641; FB_Wurth_WE-CBF-0603_W2.6; tolerance ±25%; Part Number 742792641; LCSC C2649308
J13: MUSBD11130; USB_B_Amphenol_MUSBD11130
L4: Choke_Wurth_WE-CNSW_744232090; L_CommonMode_Wurth_WE-CNSW-1206; voltage 50V; manufacturer_pn 744232090; LCSC C2649327

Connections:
/Microcontroller Circuitry/USB_D+: L4.1; also elsewhere on the board
/Microcontroller Circuitry/USB_D-: L4.4; also elsewhere on the board
/USB Interface/VBUS_RAW: D14.5 (VDD), FB1.2, J13.1 (VBUS)
GND: D14.2 (GND), J13.4 (GND), J13.S1, J13.S2; also elsewhere on the board
unnamed: D14.3 (I/O_1), J13.3 (D+), L4.2
unnamed: D14.4 (I/O_2), J13.2 (D-), L4.3
VBUS: FB1.1; also elsewhere on the board

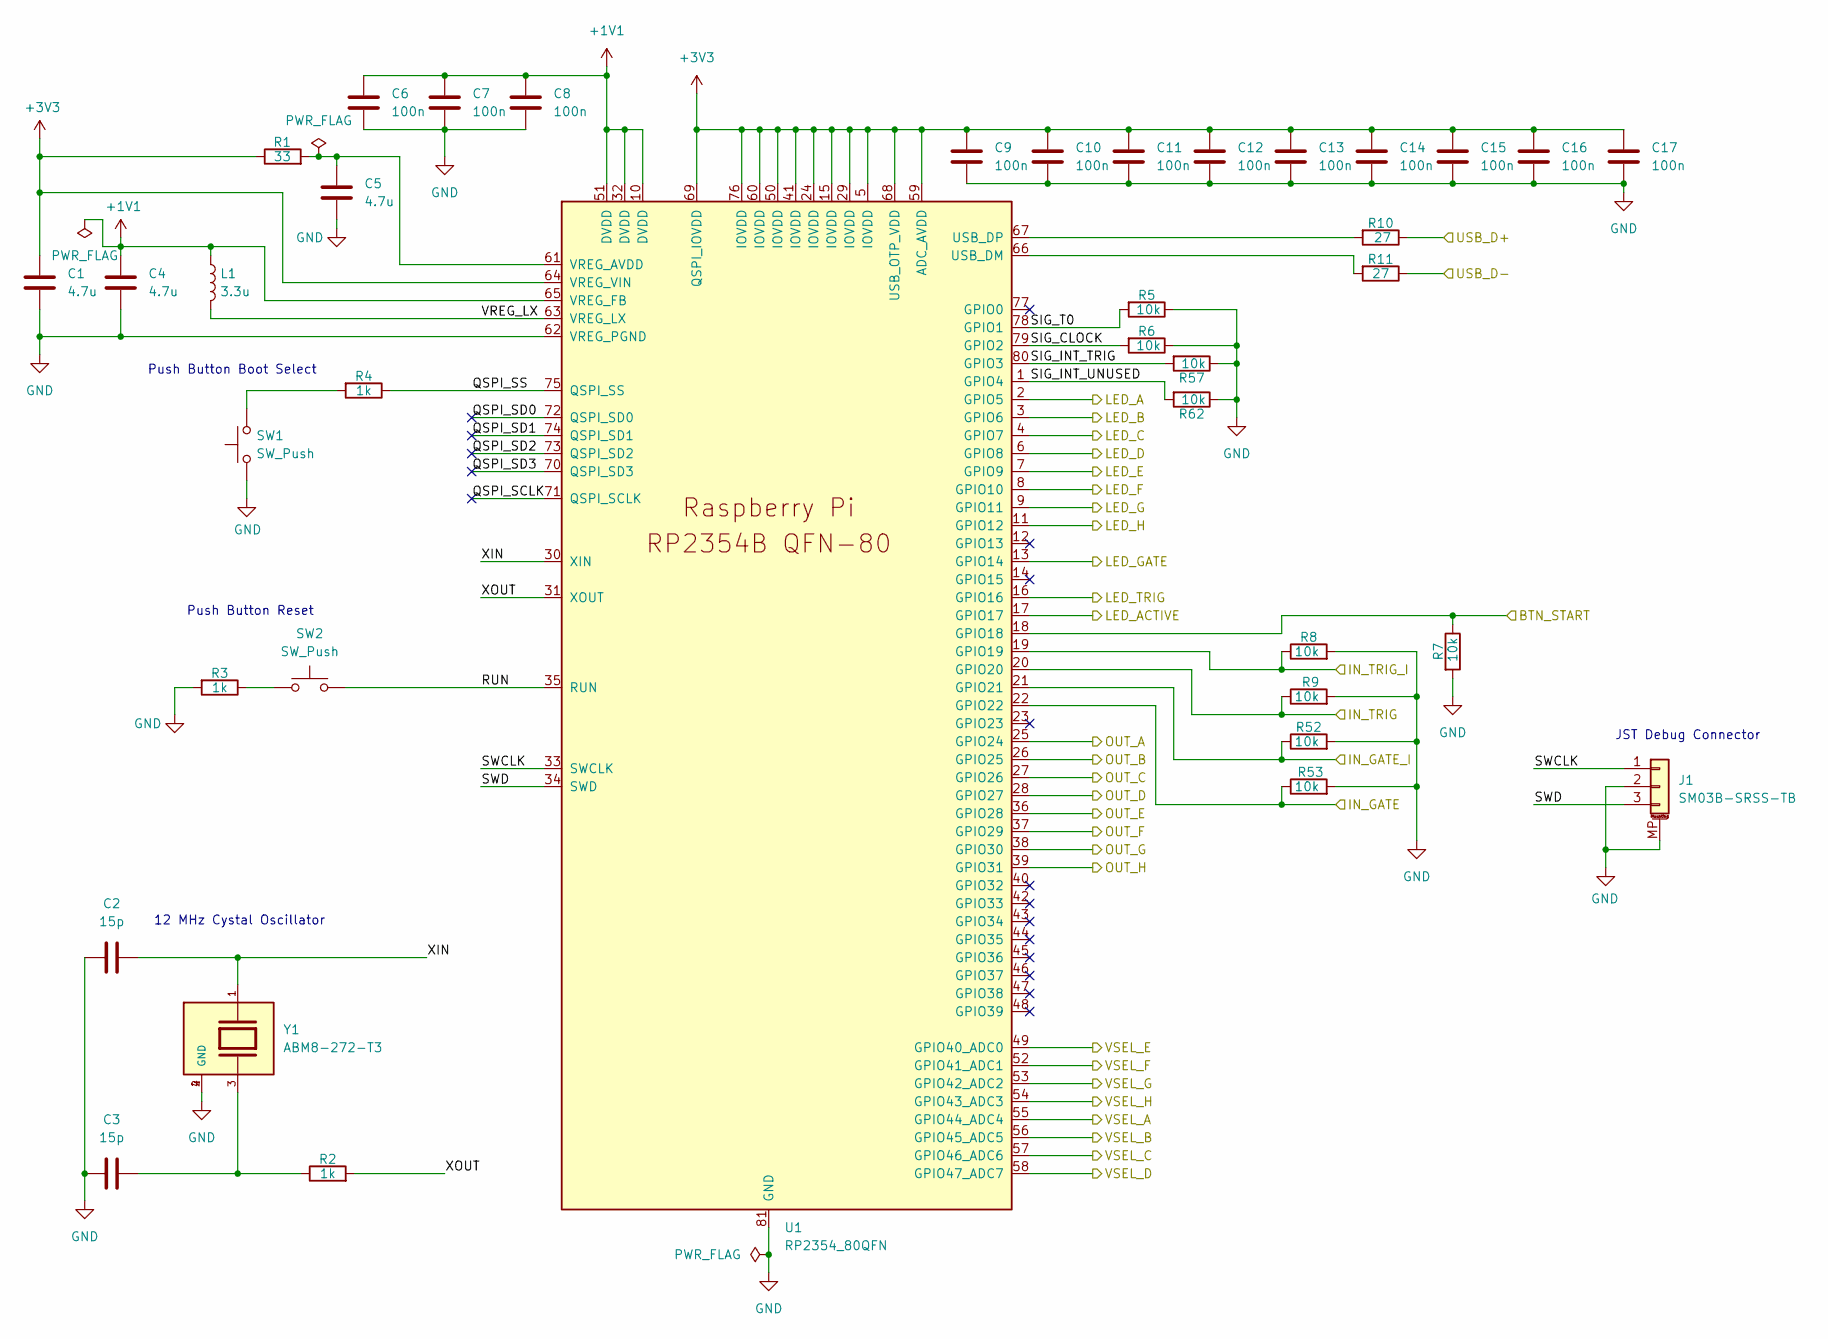
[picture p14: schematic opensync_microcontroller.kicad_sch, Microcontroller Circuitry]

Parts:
C1, C4, C5: 4.7u; C_0402_1005Metric_small_pads; voltage 10V; tolerance ±10%; manufacturer_pn C1005X5R1A475KTJ00E; LCSC C342983
C2, C3: 15p; C_0402_1005Metric_small_pads; voltage 50V; tolerance ±5%; manufacturer_pn CGA2B2C0G1H150JT0Y0F; LCSC C338103
C6, C7, C8, C9, C10, C11, C12, C13, C14, C15, C16, C17: 100n; C_0402_1005Metric_small_pads; voltage 50V; tolerance ±10%; manufacturer_pn CGA2B3X7R1H104KT0Y0F; LCSC C343042
J1: SM03B-SRSS-TB; JST_SH_SM03B-SRSS-TB_1x03-1MP_P1.00mm_Horizontal; voltage 50V; manufacturer_pn SM03B-SRSS-TB(LF)(SN); LCSC C160403
L1: 3.3u; L_pol_2016; manufacturer_pn AOTA-B201610S3R3-101-T; LCSC C42411119
R1: 33; R_0402_1005Metric; tolerance ±1%; manufacturer_pn CRCW040233R0FKEDC; LCSC C844506
R2, R3, R4: 1k; R_0402_1005Metric; tolerance ±1%; voltage 50V; manufacturer_pn CRCW04021K00FKEDHP; LCSC C313354
R5, R6, R7, R8, R9, R52, R53, R57, R62: 10k; R_0402_1005Metric; tolerance ±1%; voltage 50V; manufacturer_pn CRCW040210K0FKED; LCSC C71617
R10, R11: 27; R_0402_1005Metric; tolerance ±1%; manufacturer_pn CRCW040227R0FKEDC; LCSC C4162575
SW1, SW2: SW_Push; SW_Push_1P1T_NO_Vertical_Wuerth_434133025816; voltage 16V; manufacturer_pn 434133025816; LCSC C5504987
U1: RP2354_80QFN; RP2350-QFN-80-1EP_10x10_P0.4mm_EP3.4x3.4mm_ThermalVias; manufacturer_pn RP2354B; LCSC C39843328
Y1: ABM8-272-T3; XTAL_ABM8-272-T3; PARTREV 07-29-20; LCSC C20625731

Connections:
+1V1: C4.1, C6.1, C7.1, C8.1, L1.1, U1.10 (DVDD), U1.32 (DVDD), U1.51 (DVDD), U1.65 (VREG_FB)
+3V3: C1.1, C9.1, C10.1, C11.1, C12.1, C13.1, C14.1, C15.1, C16.1, C17.1, R1.1, U1.5 (IOVDD), U1.15 (IOVDD), U1.24 (IOVDD), U1.29 (IOVDD), U1.41 (IOVDD), U1.50 (IOVDD), U1.59 (ADC_AVDD), U1.60 (IOVDD), U1.64 (VREG_VIN), U1.68 (USB_OTP_VDD), U1.69 (QSPI_IOVDD), U1.76 (IOVDD); also elsewhere on the board
/IN_G: R53.1, U1.22 (GPIO22); also elsewhere on the board
/IN_G_INV: R52.1, U1.21 (GPIO21); also elsewhere on the board
/IN_T: R9.1, U1.20 (GPIO20); also elsewhere on the board
/IN_T_INV: R8.1, U1.19 (GPIO19); also elsewhere on the board
/Indicator Panel/BTN_START: R7.1, U1.18 (GPIO18); also elsewhere on the board
/Indicator Panel/LED_A: U1.2 (GPIO5); also elsewhere on the board
/Indicator Panel/LED_ACTIVE: U1.17 (GPIO17); also elsewhere on the board
/Indicator Panel/LED_B: U1.3 (GPIO6); also elsewhere on the board
/Indicator Panel/LED_C: U1.4 (GPIO7); also elsewhere on the board
/Indicator Panel/LED_D: U1.6 (GPIO8); also elsewhere on the board
/Indicator Panel/LED_E: U1.7 (GPIO9); also elsewhere on the board
/Indicator Panel/LED_F: U1.8 (GPIO10); also elsewhere on the board
/Indicator Panel/LED_G: U1.9 (GPIO11); also elsewhere on the board
/Indicator Panel/LED_GATE: U1.13 (GPIO14); also elsewhere on the board
/Indicator Panel/LED_H: U1.11 (GPIO12); also elsewhere on the board
/Indicator Panel/LED_TRIG: U1.16 (GPIO16); also elsewhere on the board
/Microcontroller Circuitry/QSPI_SCLK: U1.71 (QSPI_SCLK)
/Microcontroller Circuitry/QSPI_SD0: U1.72 (QSPI_SD0)
/Microcontroller Circuitry/QSPI_SD1: U1.74 (QSPI_SD1)
/Microcontroller Circuitry/QSPI_SD2: U1.73 (QSPI_SD2)
/Microcontroller Circuitry/QSPI_SD3: U1.70 (QSPI_SD3)
/Microcontroller Circuitry/QSPI_SS: R4.1, U1.75 (QSPI_SS)
/Microcontroller Circuitry/RUN: SW2.2, U1.35 (RUN)
/Microcontroller Circuitry/SIG_CLOCK: R6.2, U1.79 (GPIO2)
/Microcontroller Circuitry/SIG_INT_TRIG: R57.2, U1.80 (GPIO3)
/Microcontroller Circuitry/SIG_INT_UNUSED: R62.2, U1.1 (GPIO4)
/Microcontroller Circuitry/SIG_T0: R5.2, U1.78 (GPIO1)
/Microcontroller Circuitry/SWCLK: J1.1, U1.33 (SWCLK)
/Microcontroller Circuitry/SWD: J1.3, U1.34 (SWD)
/Microcontroller Circuitry/USB_D+: R10.1; also elsewhere on the board
/Microcontroller Circuitry/USB_D-: R11.1; also elsewhere on the board
/Microcontroller Circuitry/VREG_LX: L1.2, U1.63 (VREG_LX)
/Microcontroller Circuitry/XIN: C2.2, U1.30 (XIN), Y1.1
/Microcontroller Circuitry/XOUT: R2.2, U1.31 (XOUT)
/OUT_A: U1.25 (GPIO24); also elsewhere on the board
/OUT_B: U1.26 (GPIO25); also elsewhere on the board
/OUT_C: U1.27 (GPIO26); also elsewhere on the board
/OUT_D: U1.28 (GPIO27); also elsewhere on the board
/OUT_E: U1.36 (GPIO28); also elsewhere on the board
/OUT_F: U1.37 (GPIO29); also elsewhere on the board
/OUT_G: U1.38 (GPIO30); also elsewhere on the board
/OUT_H: U1.39 (GPIO31); also elsewhere on the board
/VSEL_A: U1.55 (GPIO44_ADC4); also elsewhere on the board
/VSEL_B: U1.56 (GPIO45_ADC5); also elsewhere on the board
/VSEL_C: U1.57 (GPIO46_ADC6); also elsewhere on the board
/VSEL_D: U1.58 (GPIO47_ADC7); also elsewhere on the board
/VSEL_E: U1.49 (GPIO40_ADC0); also elsewhere on the board
/VSEL_F: U1.52 (GPIO41_ADC1); also elsewhere on the board
/VSEL_G: U1.53 (GPIO42_ADC2); also elsewhere on the board
/VSEL_H: U1.54 (GPIO43_ADC3); also elsewhere on the board
GND: C1.2, C2.1, C3.1, C4.2, C5.2, C6.2, C7.2, C8.2, C9.2, C10.2, C11.2, C12.2, C13.2, C14.2, C15.2, C16.2, C17.2, J1.2, J1.MP (MountPin), R3.2, R5.1, R6.1, R7.2, R8.2, R9.2, R52.2, R53.2, R57.1, R62.1, SW1.1, U1.62 (VREG_PGND), U1.81 (GND), Y1.2 (GND), Y1.4 (GND); also elsewhere on the board
unnamed: C3.2, R2.1, Y1.3
unnamed: R3.1, SW2.1
unnamed: R4.2, SW1.2
unnamed: R11.2, U1.66 (USB_DM)
unnamed: R10.2, U1.67 (USB_DP)
unnamed: C5.1, R1.2, U1.61 (VREG_AVDD)

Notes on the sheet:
Push Button Boot Select
JST Debug Connector
12 MHz Cystal Oscillator
Push Button Reset

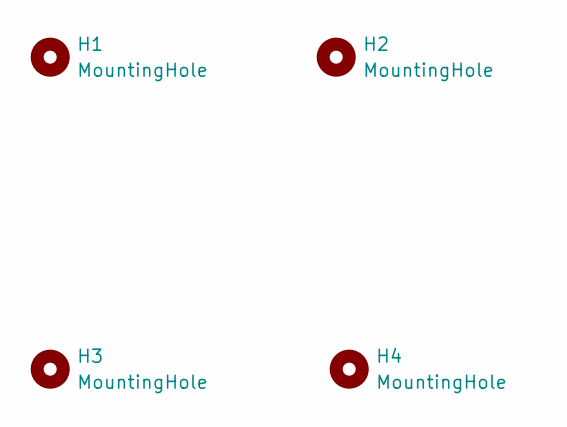
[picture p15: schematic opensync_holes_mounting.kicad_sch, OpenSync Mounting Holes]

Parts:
H1, H2, H3, H4: MountingHole; MountingHole_3.2mm_M3_ISO7380

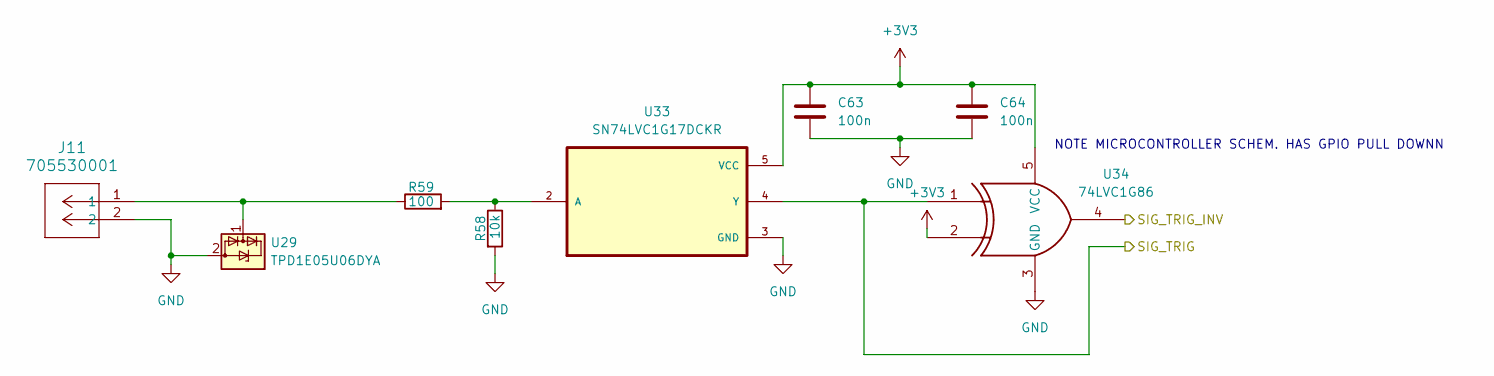
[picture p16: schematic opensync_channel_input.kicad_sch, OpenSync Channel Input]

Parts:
C63, C64: 100n; C_0402_1005Metric_small_pads; voltage 50V; tolerance ±10%; manufacturer_pn CGA2B3X7R1H104KT0Y0F; LCSC C343042
J11: 705530001; CONN_705530001_02_MOL
R58: 10k; R_0603_1608Metric; tolerance ±1%; voltage 75V; manufacturer_pn CRCW060310K0FKEA; LCSC C844918
R59: 100; R_0603_1608Metric; tolerance ±1%; voltage 75V; manufacturer_pn CRCW0603100RFKEA; LCSC C844917
U29: TPD1E05U06DYA; D_SOD-523; manufacturer_pn TPD1E05U06DYAR; LCSC C3702980
U33: SN74LVC1G17DCKR; SOT65P210X110-5N; voltage 1.65V~5.5V; manufacturer_pn SN74LVC1G17DCKR; DigiKey_Part_Number 296-11934-1-ND
U34: 74LVC1G86; SOT65P210X110-5N; voltage 1.65V~5.5V; manufacturer_pn SN74LVC1G86DCKR; LCSC C52350

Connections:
+3V3: C63.1, C64.1, U33.5 (VCC), U34.2, U34.5 (VCC); also elsewhere on the board
/IN_T: U33.4 (Y), U34.1; also elsewhere on the board
/IN_T_INV: U34.4; also elsewhere on the board
GND: C63.2, C64.2, J11.2, R58.2, U29.2 (GND), U33.3 (GND), U34.3 (GND); also elsewhere on the board
unnamed: J11.1, R59.1, U29.1 (I/O)
unnamed: R58.1, R59.2, U33.2 (A)

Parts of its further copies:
C65, C66: 100n; C_0402_1005Metric_small_pads; voltage 50V; tolerance ±10%; manufacturer_pn CGA2B3X7R1H104KT0Y0F; LCSC C343042
J12: 705530001; CONN_705530001_02_MOL
R60: 100; R_0603_1608Metric; tolerance ±1%; voltage 75V; manufacturer_pn CRCW0603100RFKEA; LCSC C844917
R61: 10k; R_0603_1608Metric; tolerance ±1%; voltage 75V; manufacturer_pn CRCW060310K0FKEA; LCSC C844918
U30: TPD1E05U06DYA; D_SOD-523; manufacturer_pn TPD1E05U06DYAR; LCSC C3702980
U35: SN74LVC1G17DCKR; SOT65P210X110-5N; voltage 1.65V~5.5V; manufacturer_pn SN74LVC1G17DCKR; DigiKey_Part_Number 296-11934-1-ND
U36: 74LVC1G86; SOT65P210X110-5N; voltage 1.65V~5.5V; manufacturer_pn SN74LVC1G86DCKR; LCSC C52350

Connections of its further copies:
+3V3: C65.1, C66.1, U35.5 (VCC), U36.2, U36.5 (VCC); also elsewhere on the board
/IN_G: U35.4 (Y), U36.1; also elsewhere on the board
/IN_G_INV: U36.4; also elsewhere on the board
GND: C65.2, C66.2, J12.2, R61.2, U30.2 (GND), U35.3 (GND), U36.3 (GND); also elsewhere on the board
unnamed: J12.1, R60.1, U30.1 (I/O)
unnamed: R60.2, R61.1, U35.2 (A)

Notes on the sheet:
NOTE MICROCONTROLLER SCHEM. HAS GPIO PULL DOWNN

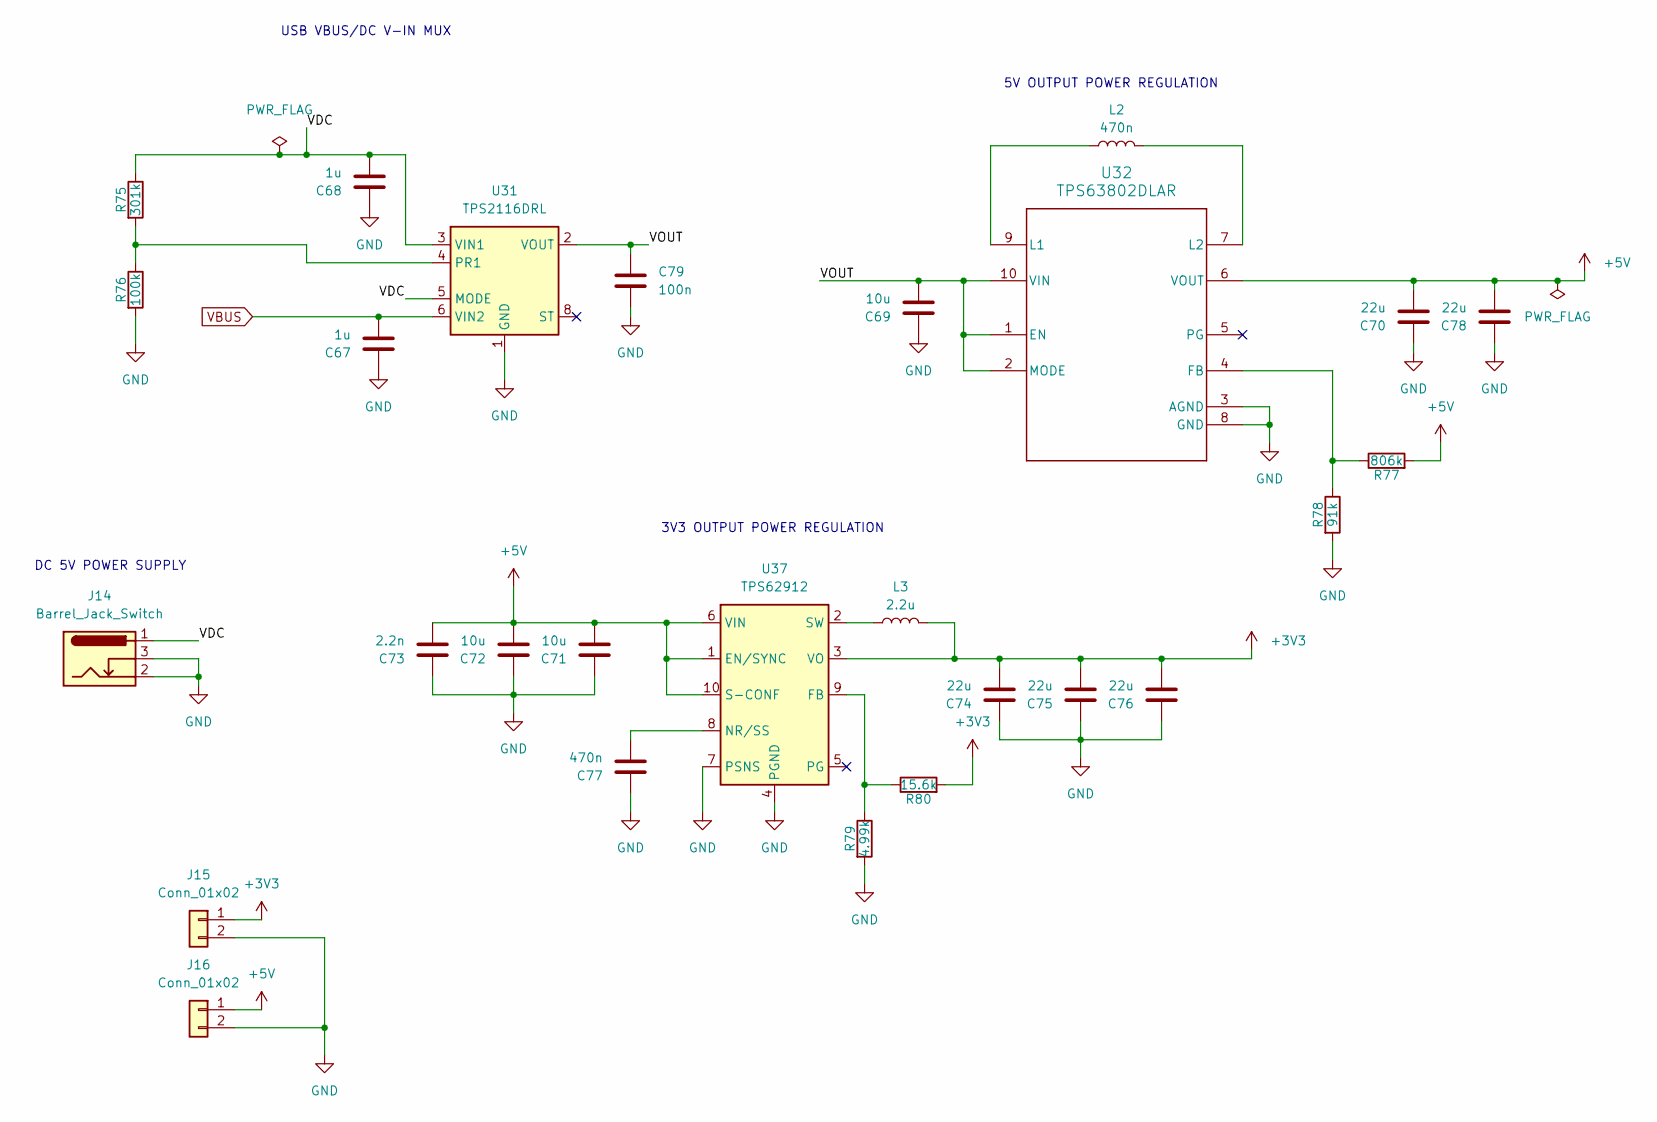
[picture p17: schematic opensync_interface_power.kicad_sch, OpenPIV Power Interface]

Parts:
C67, C68: 1u; C_0603_1608Metric; voltage 25V; tolerance ±10%; manufacturer_pn CGA3E1X7R1E105KT0Y0E; LCSC C76708
C69, C71, C72: 10u; C_0805_2012Metric; voltage 35V; tolerance ±10%; manufacturer_pn C2012X5R1V106KT000E; LCSC C342722
C70, C78: 22u; C_0805_2012Metric; voltage 35V; tolerance ±20%; manufacturer_pn C2012X5R1V226MT000E; LCSC C338080
C73: 2.2n; C_0402_1005Metric_small_pads; voltage 50V; tolerance ±10%; manufacturer_pn CGA2B2X7R1H222KT0Y0F; LCSC C338081
C74, C75, C76: 22u; C_0805_2012Metric; voltage 25V; tolerance ±20%; manufacturer_pn C2012X5R1E226MT000E; LCSC C338078
C77: 470n; C_0402_1005Metric_small_pads; voltage 16V; tolerance ±10%; manufacturer_pn CGA2B1X7S1C474KT000F; LCSC C432936
C79: 100n; C_0402_1005Metric_small_pads; voltage 50V; tolerance ±10%; manufacturer_pn CGA2B3X7R1H104KT0Y0F; LCSC C343042
J14: Barrel_Jack_Switch; BarrelJack_Wuerth_6941xx301002; manufacturer_pn 694106301002; LCSC C5441017
J15, J16: Conn_01x02; CONN-TH_705430001
L2: 470n; L_TDK_TMS252012ALM; tolerance ±20%; manufacturer_pn TMS252012ALM-R47MTAA; LCSC C24296304
L3: 2.2u; L_Wuerth_MAPI-4020; tolerance ±20%; manufacturer_pn 74438356022; LCSC C5521727
R75: 301k; R_0402_1005Metric; tolerance ±1%; manufacturer_pn CRCW0402301KFKED; LCSC C3917912
R76: 100k; R_0402_1005Metric; tolerance ±1%; voltage 50V; manufacturer_pn CRCW0402100KFKED; LCSC C481918
R77: 806k; R_0402_1005Metric; tolerance ±1%; voltage 75V; manufacturer_pn CRCW0402806KFKED; LCSC C2076627
R78: 91k; R_0402_1005Metric; tolerance ±1%; voltage 50V; manufacturer_pn CRCW040291K0FKED; LCSC C2086333
R79: 4.99k; R_0402_1005Metric; tolerance ±1%; manufacturer_pn CRCW04024K99FKEE; LCSC C4010684
R80: 15.6k; R_0402_1005Metric; tolerance ±0.1%; voltage 50V; manufacturer_pn TNPW040215K6BEED; LCSC C2075329
U31: TPS2116DRL; SOT-583-8; manufacturer_pn TPS2116DRLR; LCSC C3235557
U32: TPS63802DLAR; DLA0010A; voltage 1.3V~5.5V; manufacturer_pn TPS63802DLAR; LCSC C2845237
U37: TPS62912; Texas_RPU0010A_VQFN-HR-10_2x2mm_P0.5mm; voltage 3V~17V; manufacturer_pn TPS62912RPUR; LCSC C3198056

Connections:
+3V3: C74.2, C75.2, C76.2, J15.1, L3.2, R80.2, U37.3 (VO); also elsewhere on the board
+5V: C70.2, C71.2, C72.2, C73.2, C78.2, J16.1, R77.2, U32.6 (VOUT), U37.1 (EN/SYNC), U37.6 (VIN), U37.10 (S-CONF); also elsewhere on the board
/Power Interface/VDC: C68.2, J14.1, R75.1, U31.3 (VIN1), U31.5 (MODE)
/Power Interface/VOUT: C69.2, C79.1, U31.2 (VOUT), U31.7 (VOUT), U32.1 (EN), U32.2 (MODE), U32.10 (VIN)
GND: C67.1, C68.1, C69.1, C70.1, C71.1, C72.1, C73.1, C74.1, C75.1, C76.1, C77.1, C78.1, C79.2, J14.2, J14.3, J15.2, J16.2, R76.2, R78.2, R79.2, U31.1 (GND), U32.3 (AGND), U32.8 (GND), U37.4 (PGND), U37.7 (PSNS); also elsewhere on the board
unnamed: R75.2, R76.1, U31.4 (PR1)
unnamed: R77.1, R78.1, U32.4 (FB)
unnamed: L2.1, U32.9 (L1)
unnamed: L2.2, U32.7 (L2)
unnamed: R79.1, R80.1, U37.9 (FB)
unnamed: C77.2, U37.8 (NR/SS)
unnamed: L3.1, U37.2 (SW)
VBUS: C67.2, U31.6 (VIN2); also elsewhere on the board

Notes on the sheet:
3V3 OUTPUT POWER REGULATION
DC 5V POWER SUPPLY
USB VBUS/DC V-IN MUX
5V OUTPUT POWER REGULATION

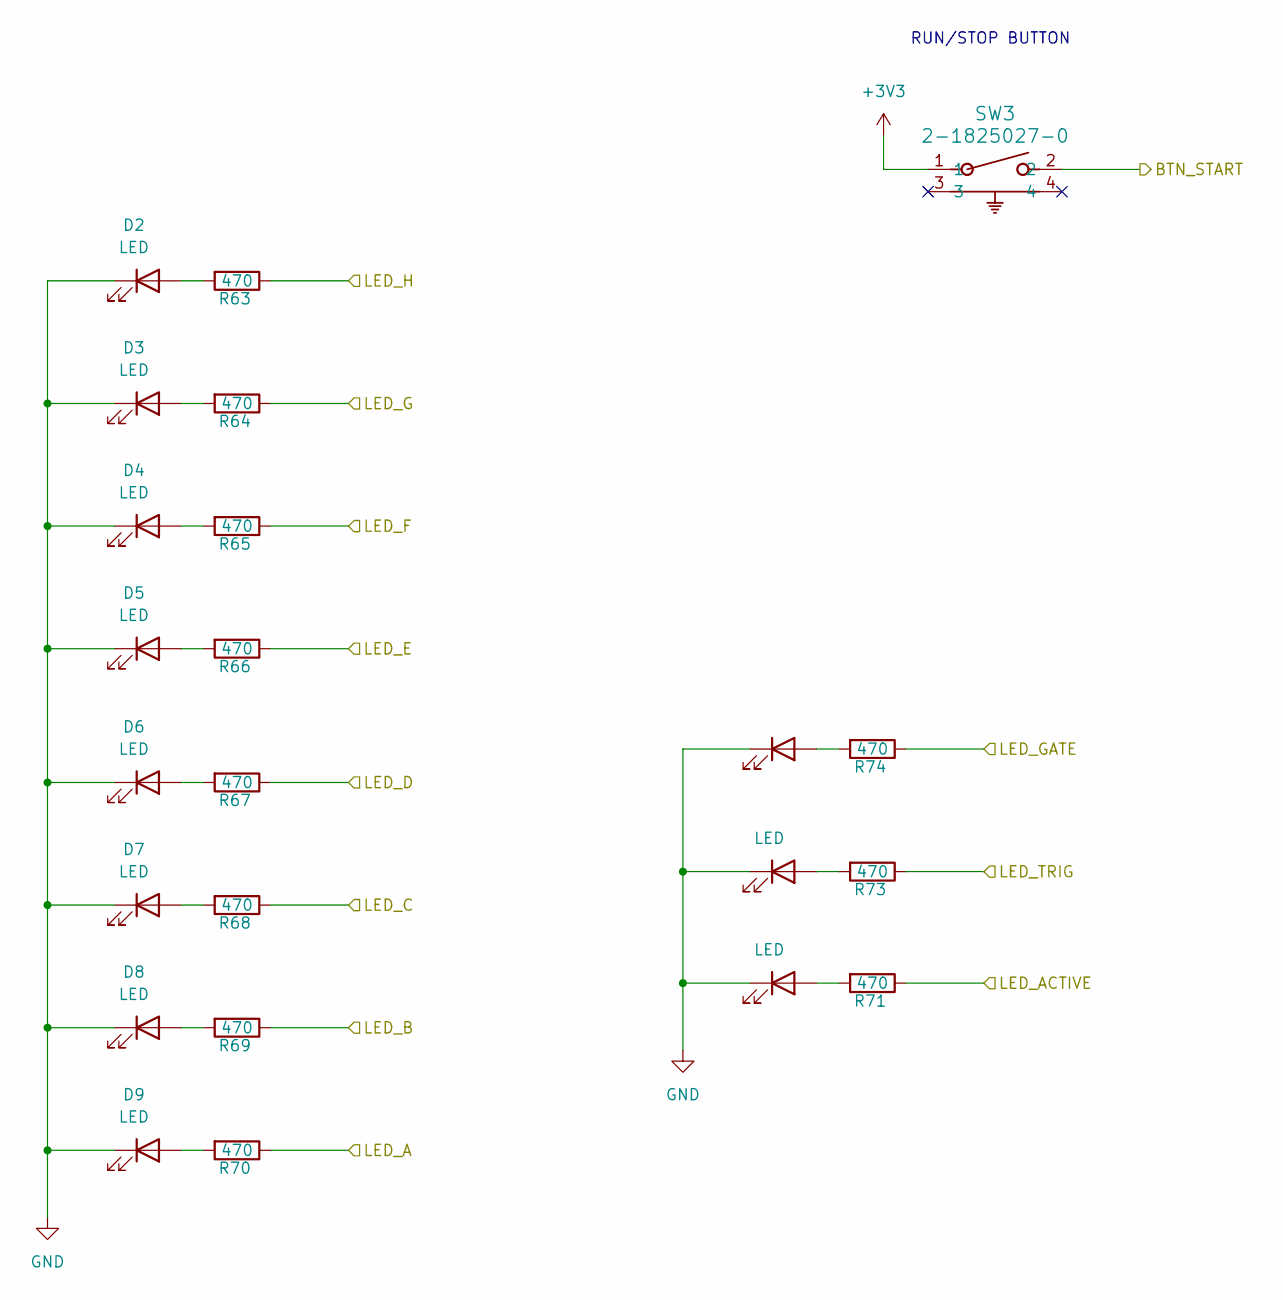
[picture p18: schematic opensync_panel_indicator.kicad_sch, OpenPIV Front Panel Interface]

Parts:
D2, D3, D4, D5, D6, D7, D8, D9, D10, D12, D13: LED; LED-SMD_L4.0-W3.6_A67F-U2BA-1-3A4B-30-R33; manufacturer_pn XL-C4040UGC; LCSC C7545687
R63, R64, R65, R66, R67, R68, R69, R70, R71, R73, R74: 470; R_0603_1608Metric; tolerance ±1%; voltage 75V; manufacturer_pn CRCW0603470RFKEA; LCSC C844786
SW3: 2-1825027-0; SW2_1825027-G_TEC; voltage 24V; manufacturer_pn 2-1825027-0; LCSC C590206

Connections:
+3V3: SW3.1; also elsewhere on the board
/Indicator Panel/BTN_START: SW3.2; also elsewhere on the board
/Indicator Panel/LED_A: R70.1; also elsewhere on the board
/Indicator Panel/LED_ACTIVE: R71.1; also elsewhere on the board
/Indicator Panel/LED_B: R69.1; also elsewhere on the board
/Indicator Panel/LED_C: R68.1; also elsewhere on the board
/Indicator Panel/LED_D: R67.1; also elsewhere on the board
/Indicator Panel/LED_E: R66.1; also elsewhere on the board
/Indicator Panel/LED_F: R65.1; also elsewhere on the board
/Indicator Panel/LED_G: R64.1; also elsewhere on the board
/Indicator Panel/LED_GATE: R74.1; also elsewhere on the board
/Indicator Panel/LED_H: R63.1; also elsewhere on the board
/Indicator Panel/LED_TRIG: R73.1; also elsewhere on the board
GND: D2.1 (K), D3.1 (K), D4.1 (K), D5.1 (K), D6.1 (K), D7.1 (K), D8.1 (K), D9.1 (K), D10.1 (K), D12.1 (K), D13.1 (K); also elsewhere on the board
unnamed: D2.2 (A), R63.2
unnamed: D3.2 (A), R64.2
unnamed: D4.2 (A), R65.2
unnamed: D5.2 (A), R66.2
unnamed: D6.2 (A), R67.2
unnamed: D7.2 (A), R68.2
unnamed: D8.2 (A), R69.2
unnamed: D9.2 (A), R70.2
unnamed: D10.2 (A), R71.2
unnamed: D12.2 (A), R73.2
unnamed: D13.2 (A), R74.2

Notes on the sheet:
RUN/STOP BUTTON

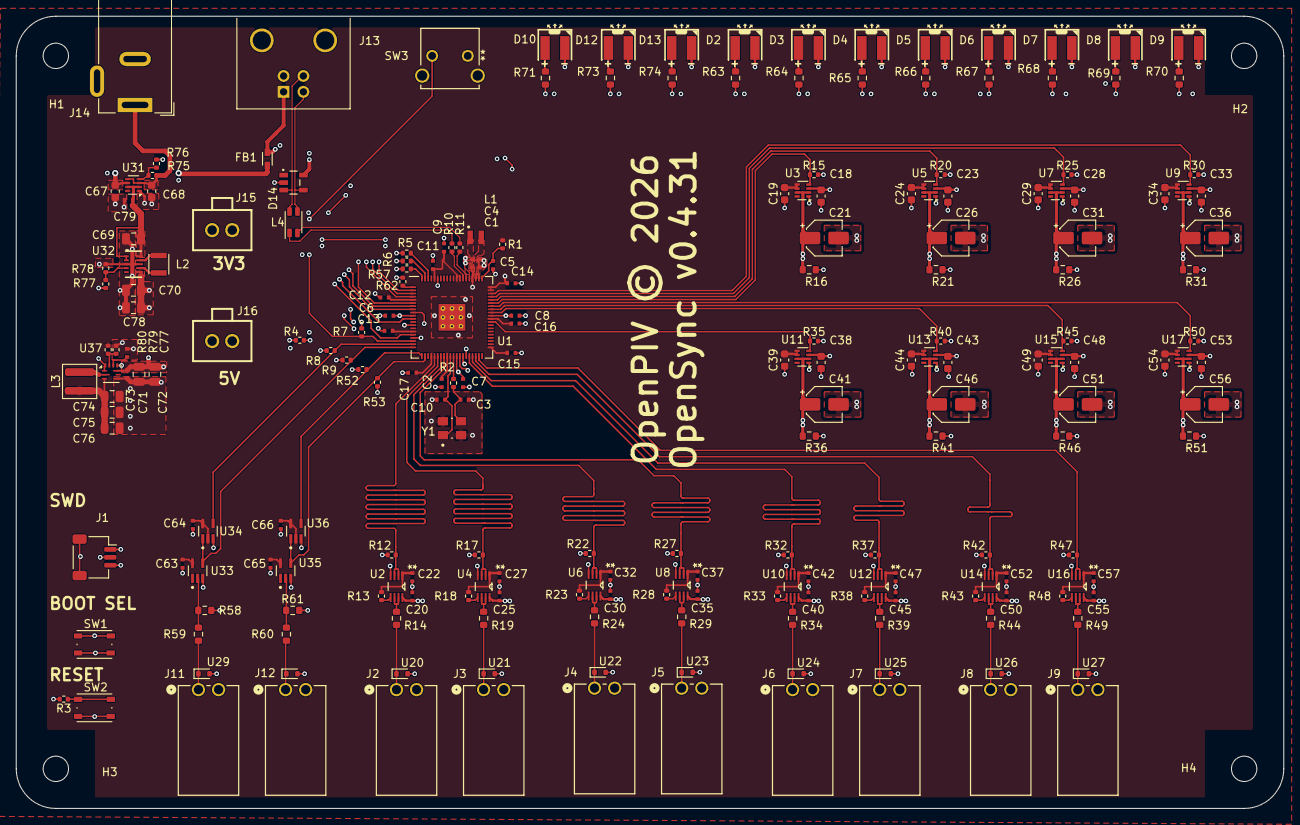
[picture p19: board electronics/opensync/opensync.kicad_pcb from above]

Board: 4 copper layers, 160.0 x 100.0 mm, 224 parts (0 on the bottom side), 115 nets.

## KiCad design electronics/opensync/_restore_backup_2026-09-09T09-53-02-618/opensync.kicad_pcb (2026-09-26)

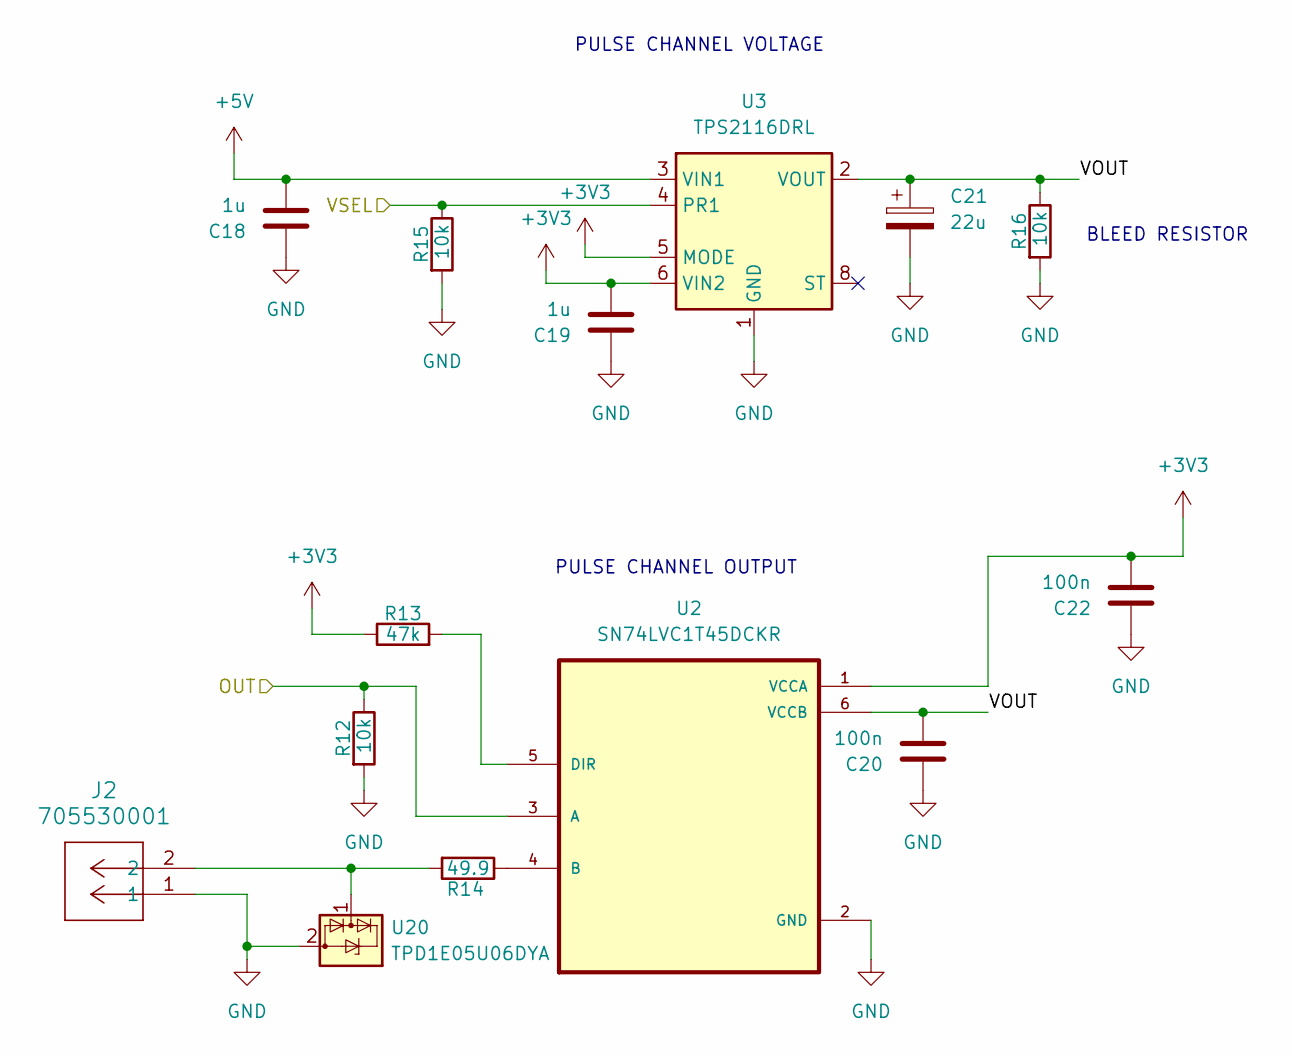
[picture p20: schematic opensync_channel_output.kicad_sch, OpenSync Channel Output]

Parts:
C18, C19: 1u; C_0402_1005Metric_small_pads
C20, C22: 100n; C_0402_1005Metric_small_pads; LCSC C60474
C21: 22u; CP_Elec_4x5.4
J2: 705530001; CONN_705530001_02_MOL; LCSC C564143
R12, R15: 10k; R_0402_1005Metric; LCSC C71617
R13: 47k; R_0402_1005Metric; LCSC C176117
R14: 49.9; R_0603_1608Metric; LCSC C1858992
R16: 10k; R_0402_1005Metric
U2: SN74LVC1T45DCKR; SOT65P210X110-6N; LCSC C9382
U3: TPS2116DRL; SOT-583-8
U20: TPD1E05U06DYA; D_SOD-523

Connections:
+3V3: C19.2, C22.2, R13.1, U2.1 (VCCA), U3.5 (MODE), U3.6 (VIN2); also elsewhere on the board
+5V: C18.2, U3.3 (VIN1); also elsewhere on the board
/OUT_A: R12.1, U2.3 (A); also elsewhere on the board
/Output Channel 1/VOUT: C20.2, C21.1, R16.1, U2.6 (VCCB), U3.2 (VOUT), U3.7 (VOUT)
/VSEL_A: R15.1, U3.4 (PR1); also elsewhere on the board
GND: C18.1, C19.1, C20.1, C21.2, C22.1, J2.1, R12.2, R15.2, R16.2, U2.2 (GND), U3.1 (GND), U20.2 (GND); also elsewhere on the board
unnamed: R14.1, U2.4 (B)
unnamed: R13.2, U2.5 (DIR)
unnamed: J2.2, R14.2, U20.1 (I/O)

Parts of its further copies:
C23, C24, C28, C29, C33, C34, C38, C39, C43, C44, C48, C49, C53, C54, C58, C59: 1u; C_0402_1005Metric_small_pads
C25, C27, C30, C32, C35, C37, C40, C42, C45, C47, C50, C52, C55, C57, C60, C62: 100n; C_0402_1005Metric_small_pads; LCSC C60474
C26, C31, C36, C41, C46, C51, C56, C61: 22u; CP_Elec_4x5.4
J3, J4, J5, J6, J7, J8, J9, J10: 705530001; CONN_705530001_02_MOL; LCSC C564143
R17, R20, R22, R25, R27, R30, R32, R35, R37, R40, R42, R45, R47, R50, R52, R55: 10k; R_0402_1005Metric; LCSC C71617
R18, R23, R28, R33, R38, R43, R48, R53: 47k; R_0402_1005Metric; LCSC C176117
R19, R24, R29, R34, R39, R44, R49, R54: 49.9; R_0603_1608Metric; LCSC C1858992
R21, R26, R31, R36, R41, R46, R51, R56: 10k; R_0402_1005Metric
U4, U6, U8, U10, U12, U14, U16, U18: SN74LVC1T45DCKR; SOT65P210X110-6N; LCSC C9382
U5, U7, U9, U11, U13, U15, U17, U19: TPS2116DRL; SOT-583-8
U21, U22, U23, U24, U25, U26, U27, U28: TPD1E05U06DYA; D_SOD-523

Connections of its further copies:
+3V3: C24.2, C27.2, C29.2, C32.2, C34.2, C37.2, C39.2, C42.2, C44.2, C47.2, C49.2, C52.2, C54.2, C57.2, C59.2, C62.2, R18.1, R23.1, R28.1, R33.1, R38.1, R43.1, R48.1, R53.1, U4.1 (VCCA), U5.5 (MODE), U5.6 (VIN2), U6.1 (VCCA), U7.5 (MODE), U7.6 (VIN2), U8.1 (VCCA), U9.5 (MODE), U9.6 (VIN2), U10.1 (VCCA), U11.5 (MODE), U11.6 (VIN2), U12.1 (VCCA), U13.5 (MODE), U13.6 (VIN2), U14.1 (VCCA), U15.5 (MODE), U15.6 (VIN2), U16.1 (VCCA), U17.5 (MODE), U17.6 (VIN2), U18.1 (VCCA), U19.5 (MODE), U19.6 (VIN2); also elsewhere on the board
+5V: C23.2, C28.2, C33.2, C38.2, C43.2, C48.2, C53.2, C58.2, U5.3 (VIN1), U7.3 (VIN1), U9.3 (VIN1), U11.3 (VIN1), U13.3 (VIN1), U15.3 (VIN1), U17.3 (VIN1), U19.3 (VIN1); also elsewhere on the board
/OUT_B: R17.1, U4.3 (A); also elsewhere on the board
/OUT_C: R22.1, U6.3 (A); also elsewhere on the board
/OUT_D: R27.1, U8.3 (A); also elsewhere on the board
/OUT_E: R32.1, U10.3 (A); also elsewhere on the board
/OUT_F: R37.1, U12.3 (A); also elsewhere on the board
/OUT_G: R42.1, U14.3 (A); also elsewhere on the board
/OUT_H: R47.1, U16.3 (A); also elsewhere on the board
/OUT_T0: R52.1, U18.3 (A); also elsewhere on the board
/Output Channel 2/VOUT: C25.2, C26.1, R21.1, U4.6 (VCCB), U5.2 (VOUT), U5.7 (VOUT)
/Output Channel 3/VOUT: C30.2, C31.1, R26.1, U6.6 (VCCB), U7.2 (VOUT), U7.7 (VOUT)
/Output Channel 4/VOUT: C35.2, C36.1, R31.1, U8.6 (VCCB), U9.2 (VOUT), U9.7 (VOUT)
/Output Channel 5/VOUT: C40.2, C41.1, R36.1, U10.6 (VCCB), U11.2 (VOUT), U11.7 (VOUT)
/Output Channel 6/VOUT: C45.2, C46.1, R41.1, U12.6 (VCCB), U13.2 (VOUT), U13.7 (VOUT)
/Output Channel 7/VOUT: C50.2, C51.1, R46.1, U14.6 (VCCB), U15.2 (VOUT), U15.7 (VOUT)
/Output Channel 8/VOUT: C55.2, C56.1, R51.1, U16.6 (VCCB), U17.2 (VOUT), U17.7 (VOUT)
/Output Channel T0/VOUT: C60.2, C61.1, R56.1, U18.6 (VCCB), U19.2 (VOUT), U19.7 (VOUT)
/VSEL_B: R20.1, U5.4 (PR1); also elsewhere on the board
/VSEL_C: R25.1, U7.4 (PR1); also elsewhere on the board
/VSEL_D: R30.1, U9.4 (PR1); also elsewhere on the board
/VSEL_E: R35.1, U11.4 (PR1); also elsewhere on the board
/VSEL_F: R40.1, U13.4 (PR1); also elsewhere on the board
/VSEL_G: R45.1, U15.4 (PR1); also elsewhere on the board
/VSEL_H: R50.1, U17.4 (PR1); also elsewhere on the board
/VSEL_T0: R55.1, U19.4 (PR1); also elsewhere on the board
GND: C23.1, C24.1, C25.1, C26.2, C27.1, C28.1, C29.1, C30.1, C31.2, C32.1, C33.1, C34.1, C35.1, C36.2, C37.1, C38.1, C39.1, C40.1, C41.2, C42.1, C43.1, C44.1, C45.1, C46.2, C47.1, C48.1, C49.1, C50.1, C51.2, C52.1, C53.1, C54.1, C55.1, C56.2, C57.1, C58.1, C59.1, C60.1, C61.2, C62.1, J3.1, J4.1, J5.1, J6.1, J7.1, J8.1, J9.1, J10.1, R17.2, R20.2, R21.2, R22.2, R25.2, R26.2, R27.2, R30.2, R31.2, R32.2, R35.2, R36.2, R37.2, R40.2, R41.2, R42.2, R45.2, R46.2, R47.2, R50.2, R51.2, R52.2, R55.2, R56.2, U4.2 (GND), U5.1 (GND), U6.2 (GND), U7.1 (GND), U8.2 (GND), U9.1 (GND), U10.2 (GND), U11.1 (GND), U12.2 (GND), U13.1 (GND), U14.2 (GND), U15.1 (GND), U16.2 (GND), U17.1 (GND), U18.2 (GND), U19.1 (GND), U21.2 (GND), U22.2 (GND), U23.2 (GND), U24.2 (GND), U25.2 (GND), U26.2 (GND), U27.2 (GND), U28.2 (GND); also elsewhere on the board
unnamed: R19.1, U4.4 (B)
unnamed: R18.2, U4.5 (DIR)
unnamed: R24.1, U6.4 (B)
unnamed: R23.2, U6.5 (DIR)
unnamed: R29.1, U8.4 (B)
unnamed: R28.2, U8.5 (DIR)
unnamed: R34.1, U10.4 (B)
unnamed: R33.2, U10.5 (DIR)
unnamed: R39.1, U12.4 (B)
unnamed: R38.2, U12.5 (DIR)
unnamed: R44.1, U14.4 (B)
unnamed: R43.2, U14.5 (DIR)
unnamed: R49.1, U16.4 (B)
unnamed: R48.2, U16.5 (DIR)
unnamed: R54.1, U18.4 (B)
unnamed: R53.2, U18.5 (DIR)
unnamed: J3.2, R19.2, U21.1 (I/O)
unnamed: J4.2, R24.2, U22.1 (I/O)
unnamed: J5.2, R29.2, U23.1 (I/O)
unnamed: J6.2, R34.2, U24.1 (I/O)
unnamed: J7.2, R39.2, U25.1 (I/O)
unnamed: J8.2, R44.2, U26.1 (I/O)
unnamed: J9.2, R49.2, U27.1 (I/O)
unnamed: J10.2, R54.2, U28.1 (I/O)

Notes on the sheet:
BLEED RESISTOR
PULSE CHANNEL OUTPUT
PULSE CHANNEL VOLTAGE

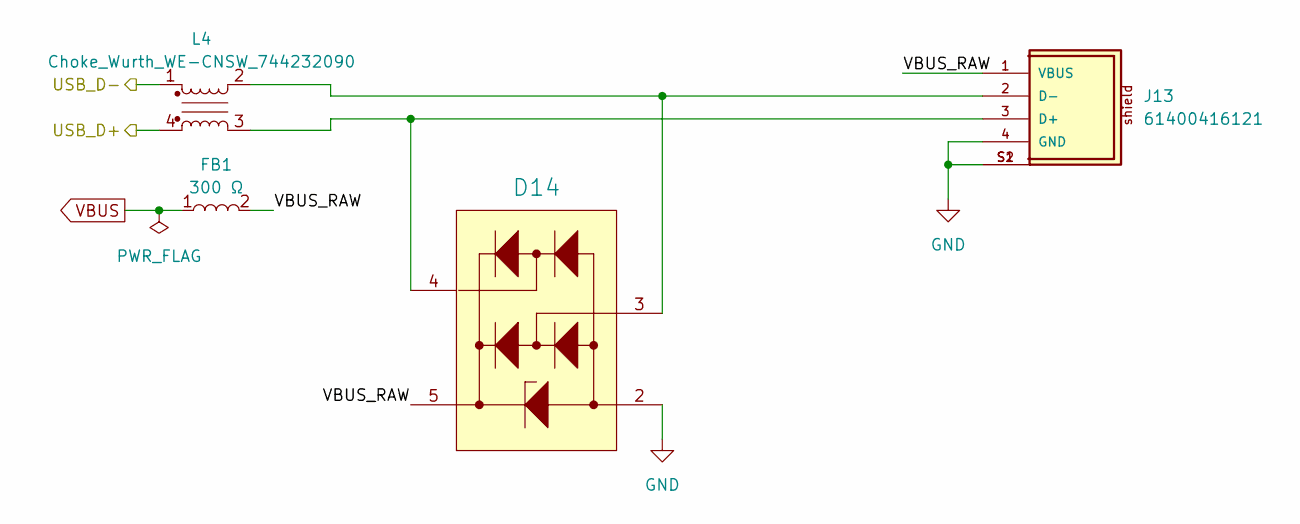
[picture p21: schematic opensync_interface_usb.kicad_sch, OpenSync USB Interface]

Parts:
D14: 5V; WE-TVS_SOT563; Manufacturer Part Number 824011
FB1: 0603_W2.6_742792641; FB_Wurth_WE-CBF-0603_W2.6; Part Number 742792641
J13: 61400416121
L4: Choke_Wurth_WE-CNSW_744232090; L_CommonMode_Wurth_WE-CNSW-1206

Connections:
/Microcontroller Circuitry/USB_D+: D14.4 (I/O_2), J13.3 (D+), L4.3; also elsewhere on the board
/Microcontroller Circuitry/USB_D-: D14.3 (I/O_1), J13.2 (D-), L4.2; also elsewhere on the board
GND: D14.2 (GND), J13.4 (GND), J13.S1, J13.S2; also elsewhere on the board
VBUS: D14.5 (VDD), FB1.2, J13.1 (VBUS); also elsewhere on the board

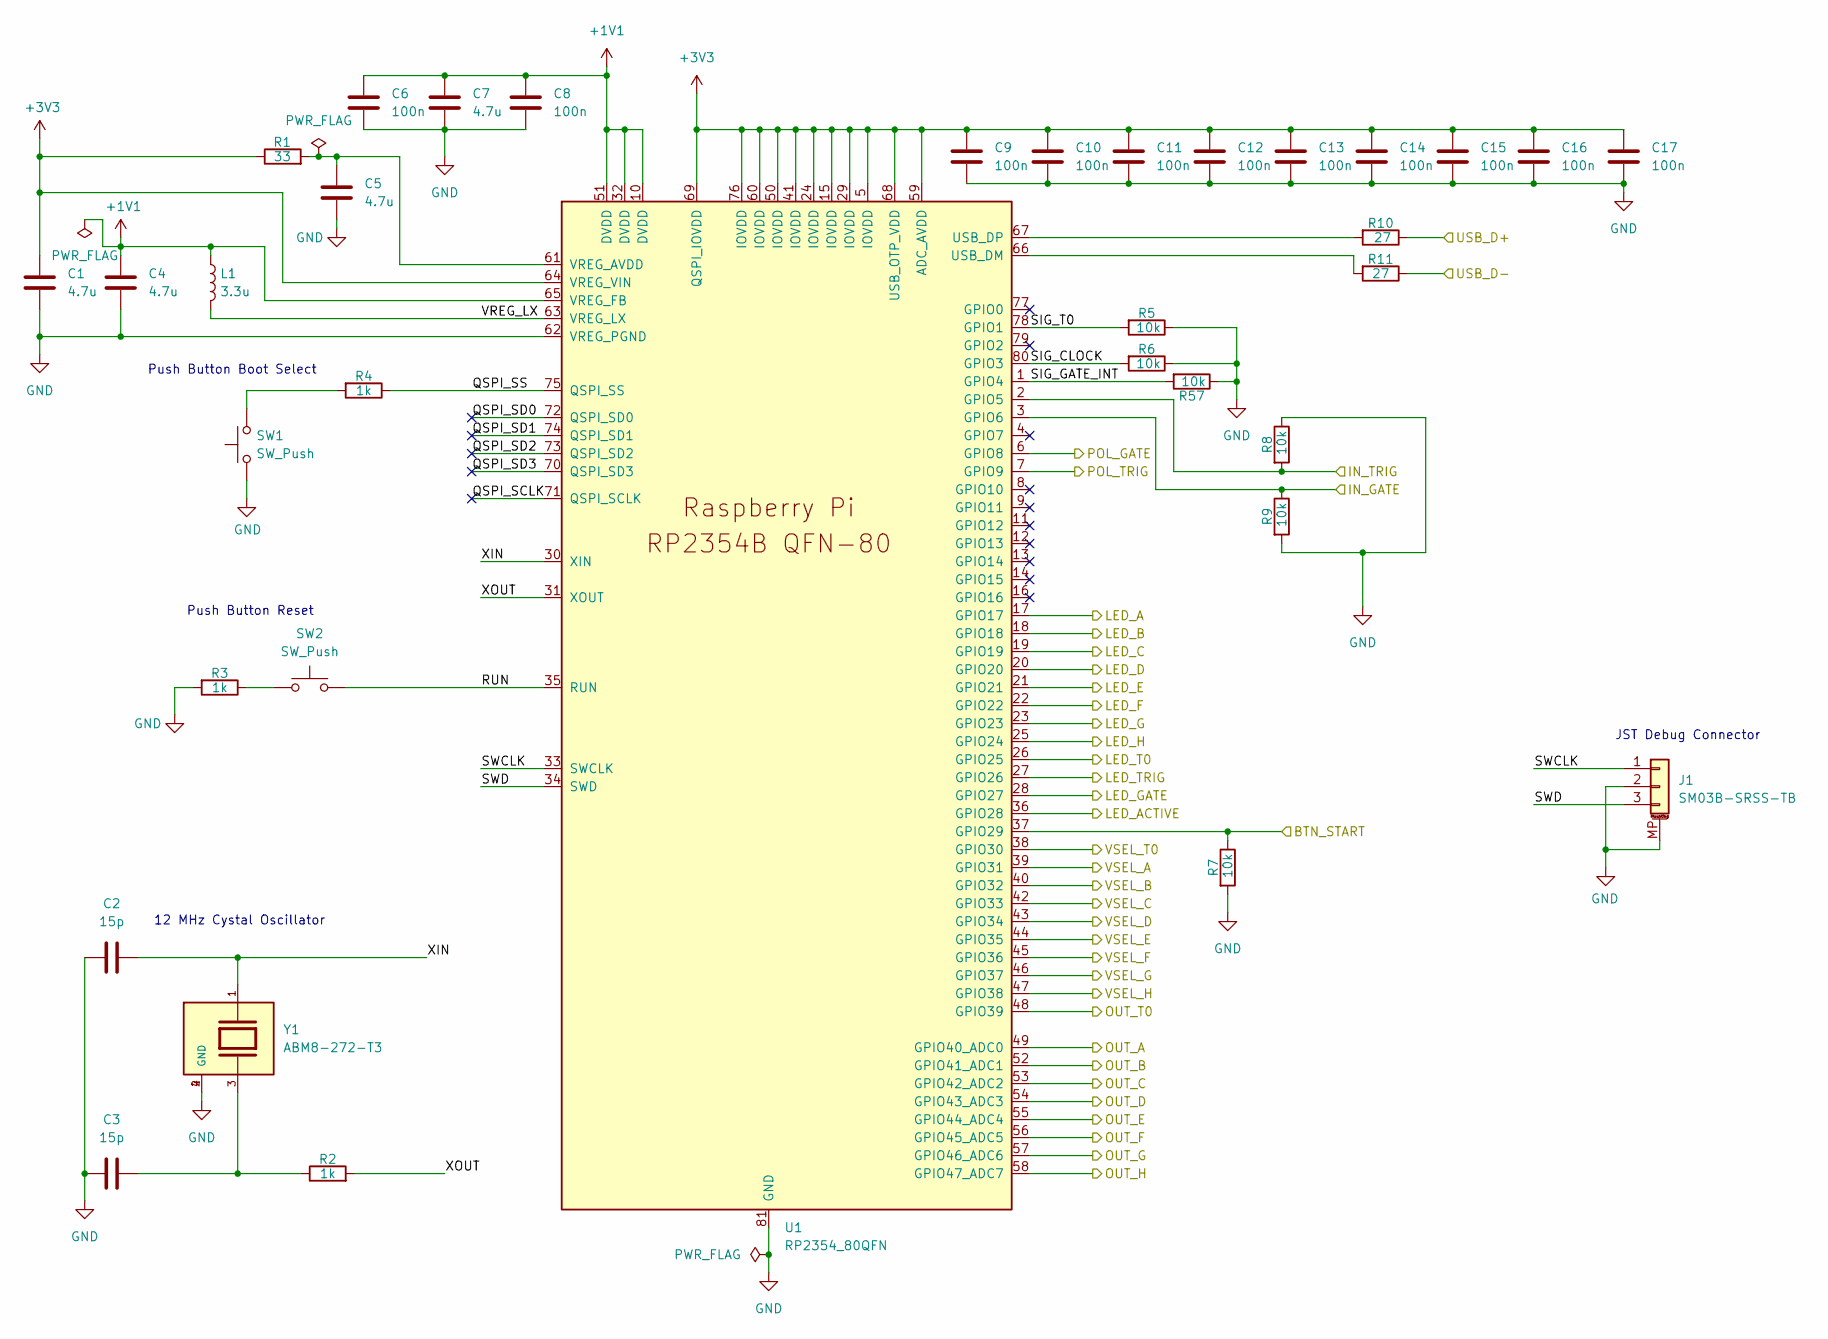
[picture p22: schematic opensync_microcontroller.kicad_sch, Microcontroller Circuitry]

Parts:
C1, C4, C5: 4.7u; C_0402_1005Metric_small_pads; LCSC C326586
C2, C3: 15p; C_0402_1005Metric_small_pads; LCSC C326803
C6, C8, C9, C10, C11, C12, C13, C14, C15, C16, C17: 100n; C_0402_1005Metric_small_pads; LCSC C60474
C7: 4.7u; C_0402_1005Metric_small_pads; LCSC C60474
J1: SM03B-SRSS-TB; JST_SH_SM03B-SRSS-TB_1x03-1MP_P1.00mm_Horizontal; LCSC C160403
L1: 3.3u; L_pol_2016; LCSC C42411119
R1: 33; R_0402_1005Metric; LCSC C844506
R2, R3, R4: 1k; R_0402_1005Metric; LCSC C313354
R5, R6, R7, R8, R9, R57: 10k; R_0402_1005Metric; LCSC C71617
R10, R11: 27; R_0402_1005Metric; LCSC C4162575
SW1, SW2: SW_Push; SW_Push_1P1T_NO_Vertical_Wuerth_434133025816; LCSC C5504987
U1: RP2354_80QFN; RP2350-QFN-80-1EP_10x10_P0.4mm_EP3.4x3.4mm_ThermalVias
Y1: ABM8-272-T3; XTAL_ABM8-272-T3; PARTREV 07-29-20

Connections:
+1V1: C4.1, C6.1, C7.1, C8.1, L1.1, U1.10 (DVDD), U1.32 (DVDD), U1.51 (DVDD), U1.65 (VREG_FB)
+3V3: C1.1, C9.1, C10.1, C11.1, C12.1, C13.1, C14.1, C15.1, C16.1, C17.1, R1.1, U1.5 (IOVDD), U1.15 (IOVDD), U1.24 (IOVDD), U1.29 (IOVDD), U1.41 (IOVDD), U1.50 (IOVDD), U1.59 (ADC_AVDD), U1.60 (IOVDD), U1.64 (VREG_VIN), U1.68 (USB_OTP_VDD), U1.69 (QSPI_IOVDD), U1.76 (IOVDD); also elsewhere on the board
/IN_G: R9.1, U1.3 (GPIO6); also elsewhere on the board
/IN_T: R8.2, U1.2 (GPIO5); also elsewhere on the board
/ISEL_G: U1.6 (GPIO8); also elsewhere on the board
/ISEL_T: U1.7 (GPIO9); also elsewhere on the board
/Indicator Panel/BTN_START: R7.1, U1.37 (GPIO29); also elsewhere on the board
/Indicator Panel/LED_A: U1.17 (GPIO17); also elsewhere on the board
/Indicator Panel/LED_ACTIVE: U1.36 (GPIO28); also elsewhere on the board
/Indicator Panel/LED_B: U1.18 (GPIO18); also elsewhere on the board
/Indicator Panel/LED_C: U1.19 (GPIO19); also elsewhere on the board
/Indicator Panel/LED_D: U1.20 (GPIO20); also elsewhere on the board
/Indicator Panel/LED_E: U1.21 (GPIO21); also elsewhere on the board
/Indicator Panel/LED_F: U1.22 (GPIO22); also elsewhere on the board
/Indicator Panel/LED_G: U1.23 (GPIO23); also elsewhere on the board
/Indicator Panel/LED_GATE: U1.28 (GPIO27); also elsewhere on the board
/Indicator Panel/LED_H: U1.25 (GPIO24); also elsewhere on the board
/Indicator Panel/LED_T0: U1.26 (GPIO25); also elsewhere on the board
/Indicator Panel/LED_TRIG: U1.27 (GPIO26); also elsewhere on the board
/Microcontroller Circuitry/QSPI_SCLK: U1.71 (QSPI_SCLK)
/Microcontroller Circuitry/QSPI_SD0: U1.72 (QSPI_SD0)
/Microcontroller Circuitry/QSPI_SD1: U1.74 (QSPI_SD1)
/Microcontroller Circuitry/QSPI_SD2: U1.73 (QSPI_SD2)
/Microcontroller Circuitry/QSPI_SD3: U1.70 (QSPI_SD3)
/Microcontroller Circuitry/QSPI_SS: R4.1, U1.75 (QSPI_SS)
/Microcontroller Circuitry/RUN: SW2.2, U1.35 (RUN)
/Microcontroller Circuitry/SIG_CLOCK: R6.2, U1.80 (GPIO3)
/Microcontroller Circuitry/SIG_GATE_INT: R57.2, U1.1 (GPIO4)
/Microcontroller Circuitry/SIG_T0: R5.2, U1.78 (GPIO1)
/Microcontroller Circuitry/SWCLK: J1.1, U1.33 (SWCLK)
/Microcontroller Circuitry/SWD: J1.3, U1.34 (SWD)
/Microcontroller Circuitry/USB_D+: R10.1; also elsewhere on the board
/Microcontroller Circuitry/USB_D-: R11.1; also elsewhere on the board
/Microcontroller Circuitry/VREG_LX: L1.2, U1.63 (VREG_LX)
/Microcontroller Circuitry/XIN: C2.2, U1.30 (XIN), Y1.1
/Microcontroller Circuitry/XOUT: R2.2, U1.31 (XOUT)
/OUT_A: U1.49 (GPIO40_ADC0); also elsewhere on the board
/OUT_B: U1.52 (GPIO41_ADC1); also elsewhere on the board
/OUT_C: U1.53 (GPIO42_ADC2); also elsewhere on the board
/OUT_D: U1.54 (GPIO43_ADC3); also elsewhere on the board
/OUT_E: U1.55 (GPIO44_ADC4); also elsewhere on the board
/OUT_F: U1.56 (GPIO45_ADC5); also elsewhere on the board
/OUT_G: U1.57 (GPIO46_ADC6); also elsewhere on the board
/OUT_H: U1.58 (GPIO47_ADC7); also elsewhere on the board
/OUT_T0: U1.48 (GPIO39); also elsewhere on the board
/VSEL_A: U1.39 (GPIO31); also elsewhere on the board
/VSEL_B: U1.40 (GPIO32); also elsewhere on the board
/VSEL_C: U1.42 (GPIO33); also elsewhere on the board
/VSEL_D: U1.43 (GPIO34); also elsewhere on the board
/VSEL_E: U1.44 (GPIO35); also elsewhere on the board
/VSEL_F: U1.45 (GPIO36); also elsewhere on the board
/VSEL_G: U1.46 (GPIO37); also elsewhere on the board
/VSEL_H: U1.47 (GPIO38); also elsewhere on the board
/VSEL_T0: U1.38 (GPIO30); also elsewhere on the board
GND: C1.2, C2.1, C3.1, C4.2, C5.2, C6.2, C7.2, C8.2, C9.2, C10.2, C11.2, C12.2, C13.2, C14.2, C15.2, C16.2, C17.2, J1.2, J1.MP (MountPin), R3.2, R5.1, R6.1, R7.2, R8.1, R9.2, R57.1, SW1.1, U1.62 (VREG_PGND), U1.81 (GND), Y1.2 (GND), Y1.4 (GND); also elsewhere on the board
unnamed: C3.2, R2.1, Y1.3
unnamed: R3.1, SW2.1
unnamed: R4.2, SW1.2
unnamed: R11.2, U1.66 (USB_DM)
unnamed: R10.2, U1.67 (USB_DP)
unnamed: C5.1, R1.2, U1.61 (VREG_AVDD)

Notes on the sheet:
Push Button Boot Select
JST Debug Connector
12 MHz Cystal Oscillator
Push Button Reset


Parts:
C63, C64: 100n; C_0402_1005Metric_small_pads; LCSC C60474
J11: 705530001; CONN_705530001_02_MOL
R58: 10k; R_0402_1005Metric; LCSC C71617
R59: 100; R_0402_1005Metric
U29: TPD1E05U06DYA; D_SOD-523
U33: SN74LVC1G17DCKR; SOT65P210X110-5N; DigiKey_Part_Number 296-11934-1-ND
U34: 74LVC1G86; SOT65P210X110-5N

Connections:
+3V3: C63.1, C64.1, U33.5 (VCC), U34.5 (VCC); also elsewhere on the board
/IN_T: U34.4; also elsewhere on the board
/ISEL_T: U34.2; also elsewhere on the board
GND: C63.2, C64.2, J11.1, R58.2, U29.2 (GND), U33.3 (GND), U34.3 (GND); also elsewhere on the board
unnamed: J11.2, R59.1, U29.1 (I/O)
unnamed: R58.1, R59.2, U33.2 (A)
unnamed: U33.4 (Y), U34.1

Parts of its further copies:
C65, C66: 100n; C_0402_1005Metric_small_pads; LCSC C60474
J12: 705530001; CONN_705530001_02_MOL
R60: 100; R_0402_1005Metric
R61: 10k; R_0402_1005Metric; LCSC C71617
U30: TPD1E05U06DYA; D_SOD-523
U35: SN74LVC1G17DCKR; SOT65P210X110-5N; DigiKey_Part_Number 296-11934-1-ND
U36: 74LVC1G86; SOT65P210X110-5N

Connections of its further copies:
+3V3: C65.1, C66.1, U35.5 (VCC), U36.5 (VCC); also elsewhere on the board
/IN_G: U36.4; also elsewhere on the board
/ISEL_G: U36.2; also elsewhere on the board
GND: C65.2, C66.2, J12.1, R61.2, U30.2 (GND), U35.3 (GND), U36.3 (GND); also elsewhere on the board
unnamed: J12.2, R60.1, U30.1 (I/O)
unnamed: R60.2, R61.1, U35.2 (A)
unnamed: U35.4 (Y), U36.1

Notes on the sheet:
NOTE MICROCONTROLLER SCHEM. HAS GPIO PULL DOWNN


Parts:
C67, C68: 1u; C_0805_2012Metric
C69, C71, C72: 10u; C_0805_2012Metric
C70, C74, C75, C76, C78: 22u; C_0805_2012Metric
C73: 2.2n; C_0402_1005Metric_small_pads
C77: 470n; C_0402_1005Metric_small_pads
C79: 100n; C_0402_1005Metric_small_pads; LCSC C60474
J14: Barrel_Jack_Switch; BarrelJack_Wuerth_6941xx301002
L2: 47n; L_Wuerth_MAPI-3020; LCSC C2045146
L3: 2.2u; L_Wuerth_MAPI-4020; LCSC C5521727
R75: 301k; R_0402_1005Metric
R76: 100k; R_0402_1005Metric
R77: 806k; R_0402_1005Metric
R78: 91k; R_0402_1005Metric
R79: 4.99k; R_0402_1005Metric
R80: 15.6k; R_0402_1005Metric
U31: TPS2116DRL; SOT-583-8
U32: TPS63802DLAR; DLA0010A
U37: TPS62912; Texas_RPU0010A_VQFN-HR-10_2x2mm_P0.5mm

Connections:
+3V3: C74.2, C75.2, C76.2, L3.2, R80.2, U37.3 (VO); also elsewhere on the board
+5V: C70.2, C71.2, C72.2, C73.2, C78.2, R77.2, U32.6 (VOUT), U37.1 (EN/SYNC), U37.6 (VIN), U37.10 (S-CONF); also elsewhere on the board
/Power Interface/VDC: C67.2, J14.1, U31.6 (VIN2)
/Power Interface/VOUT: C69.2, C79.1, U31.2 (VOUT), U31.7 (VOUT), U32.1 (EN), U32.2 (MODE), U32.10 (VIN)
GND: C67.1, C68.1, C69.1, C70.1, C71.1, C72.1, C73.1, C74.1, C75.1, C76.1, C77.1, C78.1, C79.2, J14.3, R76.2, R78.2, R79.2, U31.1 (GND), U32.3 (AGND), U32.8 (GND), U37.4 (PGND), U37.7 (PSNS); also elsewhere on the board
unnamed: R75.2, R76.1, U31.4 (PR1)
unnamed: R77.1, R78.1, U32.4 (FB)
unnamed: L2.1, U32.9 (L1)
unnamed: L2.2, U32.7 (L2)
unnamed: R79.1, R80.1, U37.9 (FB)
unnamed: C77.2, U37.8 (NR/SS)
unnamed: L3.1, U37.2 (SW)
VBUS: C68.2, R75.1, U31.3 (VIN1), U31.5 (MODE); also elsewhere on the board

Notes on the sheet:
3V3 OUTPUT POWER REGULATION
DC 5V POWER SUPPLY
USB VBUS/DC V-IN MUX
5V OUTPUT POWER REGULATION


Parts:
D1, D2, D3, D4, D5, D6, D7, D8, D9, D10, D11, D12, D13: LED; LED-SMD_L4.0-W3.6_A67F-U2BA-1-3A4B-30-R33
R62, R63, R64, R65, R66, R67, R68, R69, R70, R71, R72, R73, R74: 470; R_0402_1005Metric
SW3: 2-1825027-0; SW2_1825027-G_TEC

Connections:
+3V3: R72.1, SW3.1; also elsewhere on the board
/Indicator Panel/BTN_START: SW3.2; also elsewhere on the board
/Indicator Panel/LED_A: R70.1; also elsewhere on the board
/Indicator Panel/LED_ACTIVE: R71.1; also elsewhere on the board
/Indicator Panel/LED_B: R69.1; also elsewhere on the board
/Indicator Panel/LED_C: R68.1; also elsewhere on the board
/Indicator Panel/LED_D: R67.1; also elsewhere on the board
/Indicator Panel/LED_E: R66.1; also elsewhere on the board
/Indicator Panel/LED_F: R65.1; also elsewhere on the board
/Indicator Panel/LED_G: R64.1; also elsewhere on the board
/Indicator Panel/LED_GATE: R74.1; also elsewhere on the board
/Indicator Panel/LED_H: R63.1; also elsewhere on the board
/Indicator Panel/LED_T0: R62.1; also elsewhere on the board
/Indicator Panel/LED_TRIG: R73.1; also elsewhere on the board
GND: D1.1 (K), D2.1 (K), D3.1 (K), D4.1 (K), D5.1 (K), D6.1 (K), D7.1 (K), D8.1 (K), D9.1 (K), D10.1 (K), D11.1 (K), D12.1 (K), D13.1 (K); also elsewhere on the board
unnamed: D1.2 (A), R62.2
unnamed: D2.2 (A), R63.2
unnamed: D3.2 (A), R64.2
unnamed: D4.2 (A), R65.2
unnamed: D5.2 (A), R66.2
unnamed: D6.2 (A), R67.2
unnamed: D7.2 (A), R68.2
unnamed: D8.2 (A), R69.2
unnamed: D9.2 (A), R70.2
unnamed: D10.2 (A), R71.2
unnamed: D11.2 (A), R72.2
unnamed: D12.2 (A), R73.2
unnamed: D13.2 (A), R74.2

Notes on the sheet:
RUN/STOP BUTTON

Board: 2 copper layers, 230 parts (0 on the bottom side), 122 nets, no tracks yet.

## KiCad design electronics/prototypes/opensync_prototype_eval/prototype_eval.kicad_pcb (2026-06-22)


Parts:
LED1: 5640100132F; Manufacturer_Part_Number 5640100132F
R19, R20, R21: 120; R_0402_1005Metric; LCSC C2100747

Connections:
/Microcontroller/LED_ERROR: LED1.4 (A_YELLOW); also elsewhere on the board
/Microcontroller/LED_INTERLOCK: LED1.6 (A_RED); also elsewhere on the board
GND: R19.1, R20.2, R21.2; also elsewhere on the board
unnamed: LED1.1 (K_GREEN), R19.2
unnamed: LED1.5 (K_RED), R20.1
unnamed: LED1.3 (K_YELLOW), R21.1
PICO_3V3: LED1.2 (A_GREEN); also elsewhere on the board

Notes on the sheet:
Indicator Lights


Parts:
C1, C2: 100n; C_0402_1005Metric_small_pads; LCSC C60474
J1: 61611042121502
R1: 47k; R_0402_1005Metric; LCSC C176117
R2: 49.9; R_0402_1005Metric; LCSC C1858992
U2: SN74LVC1T45DCKR; SOT65P210X110-6N; LCSC C9382

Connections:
/Microcontroller/OUT_1: U2.3 (A); also elsewhere on the board
GND: C1.1, C2.1, J1.2, J1.3, J1.4, J1.5, U2.2 (GND); also elsewhere on the board
unnamed: J1.1, R2.2
unnamed: R2.1, U2.4 (B)
unnamed: R1.2, U2.5 (DIR)
PICO_3V3: C2.2, R1.1, U2.1 (VCCA); also elsewhere on the board
PICO_5V: C1.2, U2.6 (VCCB); also elsewhere on the board

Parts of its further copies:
C3, C4, C5, C6, C7, C8, C9, C10, C11, C12, C13, C14, C15, C16: 100n; C_0402_1005Metric_small_pads; LCSC C60474
J2, J3, J4, J5, J6, J7, J8: 61611042121502
R3, R5, R7, R9, R11, R13, R15: 47k; R_0402_1005Metric; LCSC C176117
R4, R6, R8, R10, R12, R14, R16: 49.9; R_0402_1005Metric; LCSC C1858992
U3, U4, U5, U6, U7, U8, U9: SN74LVC1T45DCKR; SOT65P210X110-6N; LCSC C9382

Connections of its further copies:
/Microcontroller/OUT_2: U3.3 (A); also elsewhere on the board
/Microcontroller/OUT_3: U4.3 (A); also elsewhere on the board
/Microcontroller/OUT_4: U5.3 (A); also elsewhere on the board
/Microcontroller/OUT_5: U6.3 (A); also elsewhere on the board
/Microcontroller/OUT_6: U7.3 (A); also elsewhere on the board
/Microcontroller/OUT_7: U8.3 (A); also elsewhere on the board
/Microcontroller/OUT_8: U9.3 (A); also elsewhere on the board
GND: C3.1, C4.1, C5.1, C6.1, C7.1, C8.1, C9.1, C10.1, C11.1, C12.1, C13.1, C14.1, C15.1, C16.1, J2.2, J2.3, J2.4, J2.5, J3.2, J3.3, J3.4, J3.5, J4.2, J4.3, J4.4, J4.5, J5.2, J5.3, J5.4, J5.5, J6.2, J6.3, J6.4, J6.5, J7.2, J7.3, J7.4, J7.5, J8.2, J8.3, J8.4, J8.5, U3.2 (GND), U4.2 (GND), U5.2 (GND), U6.2 (GND), U7.2 (GND), U8.2 (GND), U9.2 (GND); also elsewhere on the board
unnamed: J2.1, R4.2
unnamed: J3.1, R6.2
unnamed: J4.1, R8.2
unnamed: J5.1, R10.2
unnamed: J6.1, R12.2
unnamed: J7.1, R14.2
unnamed: J8.1, R16.2
unnamed: R4.1, U3.4 (B)
unnamed: R3.2, U3.5 (DIR)
unnamed: R6.1, U4.4 (B)
unnamed: R5.2, U4.5 (DIR)
unnamed: R8.1, U5.4 (B)
unnamed: R7.2, U5.5 (DIR)
unnamed: R10.1, U6.4 (B)
unnamed: R9.2, U6.5 (DIR)
unnamed: R12.1, U7.4 (B)
unnamed: R11.2, U7.5 (DIR)
unnamed: R14.1, U8.4 (B)
unnamed: R13.2, U8.5 (DIR)
unnamed: R16.1, U9.4 (B)
unnamed: R15.2, U9.5 (DIR)
PICO_3V3: C4.2, C6.2, C8.2, C10.2, C12.2, C14.2, C16.2, R3.1, R5.1, R7.1, R9.1, R11.1, R13.1, R15.1, U3.1 (VCCA), U4.1 (VCCA), U5.1 (VCCA), U6.1 (VCCA), U7.1 (VCCA), U8.1 (VCCA), U9.1 (VCCA); also elsewhere on the board
PICO_5V: C3.2, C5.2, C7.2, C9.2, C11.2, C13.2, C15.2, U3.6 (VCCB), U4.6 (VCCB), U5.6 (VCCB), U6.6 (VCCB), U7.6 (VCCB), U8.6 (VCCB), U9.6 (VCCB); also elsewhere on the board


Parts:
J10: 61611042121502
R22: 47k; R_0402_1005Metric; LCSC C176117

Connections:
/Interlock/SAFETY_INTERLOCK: J10.1, R22.2; also elsewhere on the board
GND: J10.2, J10.3, J10.4, J10.5; also elsewhere on the board
PICO_3V3: R22.1; also elsewhere on the board

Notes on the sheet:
Safety Interlock


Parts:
C17: 100n; C_0402_1005Metric_small_pads; LCSC C60474
J9: 61611042121502
R17: 47k; R_0402_1005Metric; LCSC C176117
R18: 470; R_0402_1005Metric; LCSC C482182
U10: SN74LVC1G17DCKR; SOT65P210X110-5N; DigiKey_Part_Number 296-11934-1-ND

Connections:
/Microcontroller/IN_1: U10.4 (Y); also elsewhere on the board
GND: C17.2, J9.2, J9.3, J9.4, J9.5, R17.2, U10.3 (GND); also elsewhere on the board
unnamed: J9.1, R17.1, R18.1
unnamed: R18.2, U10.2 (A)
PICO_3V3: C17.1, U10.5 (VCC); also elsewhere on the board

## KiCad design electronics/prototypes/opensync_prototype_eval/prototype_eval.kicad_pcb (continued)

Board: 2 copper layers, 60 parts (0 on the bottom side), 44 nets, no tracks yet.

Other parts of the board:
U1: Pico; RPi_Pico_SMD

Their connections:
/Interlock/SAFETY_INTERLOCK: U1.29 (GPIO22); also elsewhere on the board
/Microcontroller/IN_1: U1.7 (GPIO5); also elsewhere on the board
/Microcontroller/LED_ERROR: U1.32 (GPIO27_ADC1); also elsewhere on the board
/Microcontroller/LED_INTERLOCK: U1.31 (GPIO26_ADC0); also elsewhere on the board
/Microcontroller/OUT_1: U1.11 (GPIO8); also elsewhere on the board
/Microcontroller/OUT_2: U1.12 (GPIO9); also elsewhere on the board
/Microcontroller/OUT_3: U1.14 (GPIO10); also elsewhere on the board
/Microcontroller/OUT_4: U1.15 (GPIO11); also elsewhere on the board
/Microcontroller/OUT_5: U1.16 (GPIO12); also elsewhere on the board
/Microcontroller/OUT_6: U1.17 (GPIO13); also elsewhere on the board
/Microcontroller/OUT_7: U1.19 (GPIO14); also elsewhere on the board
/Microcontroller/OUT_8: U1.20 (GPIO15); also elsewhere on the board
GND: U1.3 (GND), U1.8 (GND), U1.13 (GND), U1.18 (GND), U1.23 (GND), U1.28 (GND), U1.33 (AGND), U1.38 (GND), U1.42 (GND); also elsewhere on the board
PICO_3V3: U1.36 (3V3); also elsewhere on the board
PICO_5V: U1.40 (VBUS); also elsewhere on the board

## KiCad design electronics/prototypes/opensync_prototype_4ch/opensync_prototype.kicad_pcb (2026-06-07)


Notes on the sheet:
Output Ports 9 to 16 will go Here Once Designed


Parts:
C1, C4, C5: 4.7u; C_0402_1005Metric_small_pads; LCSC C326586
C2, C3: 15p; C_0402_1005Metric_small_pads; LCSC C326803
C6, C8, C9, C10, C11, C12, C13, C14, C15, C16, C17: 100n; C_0402_1005Metric_small_pads; LCSC C60474
C7: 4.7u; C_0402_1005Metric_small_pads; LCSC C60474
J12: SM03B-SRSS-TB; JST_SH_SM03B-SRSS-TB_1x03-1MP_P1.00mm_Horizontal; LCSC C160403
L1: 3.3u; L_pol_2016; LCSC C42411119
R1: 33; R_0402_1005Metric; LCSC C844506
R2, R3, R4: 1k; R_0402_1005Metric; LCSC C313354
R5, R6, R7, R10, R17, R18, R19, R20: 10k; R_0402_1005Metric; LCSC C71617
R11, R12: 27; R_0402_1005Metric; LCSC C4162575
SW1, SW2: SW_Push; SW_Push_1P1T_NO_Vertical_Wuerth_434133025816; LCSC C5504987
U2: RP2354_80QFN; RP2350-QFN-80-1EP_10x10_P0.4mm_EP3.4x3.4mm_ThermalVias; LCSC C39843328
Y1: ABM8-272-T3; XTAL_ABM8-272-T3; PARTREV 07-29-20; LCSC C20625731

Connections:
+1V1: C4.1, C6.1, C7.1, C8.1, L1.1, U2.10 (DVDD), U2.32 (DVDD), U2.51 (DVDD), U2.65 (VREG_FB)
+3V3: C1.1, C9.1, C10.1, C11.1, C12.1, C13.1, C14.1, C15.1, C16.1, C17.1, R1.1, U2.5 (IOVDD), U2.15 (IOVDD), U2.24 (IOVDD), U2.29 (IOVDD), U2.41 (IOVDD), U2.50 (IOVDD), U2.59 (ADC_AVDD), U2.60 (IOVDD), U2.64 (VREG_VIN), U2.68 (USB_OTP_VDD), U2.69 (QSPI_IOVDD), U2.76 (IOVDD); also elsewhere on the board
/LEDs and Interlock/ERROR_LED: U2.54 (GPIO43_ADC3); also elsewhere on the board
/LEDs and Interlock/INTERLOCK_LED: U2.55 (GPIO44_ADC4); also elsewhere on the board
/LEDs and Interlock/SAFETY_INTERLOCK: U2.56 (GPIO45_ADC5); also elsewhere on the board
/Microcontroller and Ext. Clock/CLOCK_1: R5.2, U2.78 (GPIO1)
/Microcontroller and Ext. Clock/CLOCK_2: R10.2, U2.79 (GPIO2)
/Microcontroller and Ext. Clock/CLOCK_3: R6.2, U2.80 (GPIO3)
/Microcontroller and Ext. Clock/OUTPUT_1: R17.1, U2.26 (GPIO25); also elsewhere on the board
/Microcontroller and Ext. Clock/OUTPUT_2: R18.1, U2.27 (GPIO26); also elsewhere on the board
/Microcontroller and Ext. Clock/OUTPUT_3: R19.1, U2.28 (GPIO27); also elsewhere on the board
/Microcontroller and Ext. Clock/OUTPUT_4: R20.1, U2.36 (GPIO28); also elsewhere on the board
/Microcontroller and Ext. Clock/OUTPUT_5: U2.37 (GPIO29)
/Microcontroller and Ext. Clock/OUTPUT_6: U2.38 (GPIO30)
/Microcontroller and Ext. Clock/OUTPUT_7: U2.39 (GPIO31)
/Microcontroller and Ext. Clock/OUTPUT_8: U2.40 (GPIO32)
/Microcontroller and Ext. Clock/OUTPUT_9: U2.42 (GPIO33)
/Microcontroller and Ext. Clock/OUTPUT_10: U2.43 (GPIO34)
/Microcontroller and Ext. Clock/OUTPUT_11: U2.44 (GPIO35)
/Microcontroller and Ext. Clock/OUTPUT_12: U2.45 (GPIO36)
/Microcontroller and Ext. Clock/OUTPUT_13: U2.46 (GPIO37)
/Microcontroller and Ext. Clock/OUTPUT_14: U2.47 (GPIO38)
/Microcontroller and Ext. Clock/OUTPUT_15: U2.48 (GPIO39)
/Microcontroller and Ext. Clock/OUTPUT_16: U2.49 (GPIO40_ADC0)
/Microcontroller and Ext. Clock/QSPI_SCLK: U2.71 (QSPI_SCLK)
/Microcontroller and Ext. Clock/QSPI_SD0: U2.72 (QSPI_SD0)
/Microcontroller and Ext. Clock/QSPI_SD1: U2.74 (QSPI_SD1)
/Microcontroller and Ext. Clock/QSPI_SD2: U2.73 (QSPI_SD2)
/Microcontroller and Ext. Clock/QSPI_SD3: U2.70 (QSPI_SD3)
/Microcontroller and Ext. Clock/QSPI_SS: R4.1, U2.75 (QSPI_SS)
/Microcontroller and Ext. Clock/RUN: SW2.2, U2.35 (RUN)
/Microcontroller and Ext. Clock/SWCLK: J12.1, U2.33 (SWCLK)
/Microcontroller and Ext. Clock/SWD: J12.3, U2.34 (SWD)
/Microcontroller and Ext. Clock/TRIGGER_1: R7.1, U2.18 (GPIO18); also elsewhere on the board
/Microcontroller and Ext. Clock/VREG_LX: L1.2, U2.63 (VREG_LX)
/Microcontroller and Ext. Clock/XIN: C2.2, U2.30 (XIN), Y1.1
/Microcontroller and Ext. Clock/XOUT: R2.2, U2.31 (XOUT)
/Power and Data/USB_D+: R11.1; also elsewhere on the board
/Power and Data/USB_D-: R12.1; also elsewhere on the board
GND: C1.2, C2.1, C3.1, C4.2, C5.2, C6.2, C7.2, C8.2, C9.2, C10.2, C11.2, C12.2, C13.2, C14.2, C15.2, C16.2, C17.2, J12.2, J12.MP (MountPin), R3.2, R5.1, R6.1, R7.2, R10.1, R17.2, R18.2, R19.2, R20.2, SW1.1, U2.62 (VREG_PGND), U2.81 (GND), Y1.2 (GND), Y1.4 (GND); also elsewhere on the board
unnamed: C3.2, R2.1, Y1.3
unnamed: R3.1, SW2.1
unnamed: R4.2, SW1.2
unnamed: R12.2, U2.66 (USB_DM)
unnamed: R11.2, U2.67 (USB_DP)
unnamed: C5.1, R1.2, U2.61 (VREG_AVDD)

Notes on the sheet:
12 MHz Cystal Oscillator
JST Debug Connector
Push Button Boot Select
Push Button Reset


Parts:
H1, H2, H3, H4: MountingHole; MountingHole_3.2mm_M3_ISO7380


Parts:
C24, C25, C26, C27, C28, C29, C30, C31: 100n; C_0402_1005Metric_small_pads; LCSC C60474
J4, J5, J6, J7: 61611042121502
R28, R30, R32, R34: 47k; R_0402_1005Metric; LCSC C176117
R29, R31, R33, R35: 49.9; R_0402_1005Metric; LCSC C1858992
U5, U6, U7, U8: SN74LVC1T45DCKR; SOT65P210X110-6N; LCSC C9382

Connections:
+3V3: C24.2, C25.2, C28.2, C29.2, R28.1, R30.1, R32.1, R34.1, U5.1 (VCCA), U6.1 (VCCA), U7.1 (VCCA), U8.1 (VCCA); also elsewhere on the board
+5V: C26.2, C27.2, C30.1, C31.2, U5.6 (VCCB), U6.6 (VCCB), U7.6 (VCCB), U8.6 (VCCB); also elsewhere on the board
/Microcontroller and Ext. Clock/OUTPUT_1: U5.3 (A); also elsewhere on the board
/Microcontroller and Ext. Clock/OUTPUT_2: U6.3 (A); also elsewhere on the board
/Microcontroller and Ext. Clock/OUTPUT_3: U7.3 (A); also elsewhere on the board
/Microcontroller and Ext. Clock/OUTPUT_4: U8.3 (A); also elsewhere on the board
GND: C24.1, C25.1, C26.1, C27.1, C28.1, C29.1, C30.2, C31.1, J4.2, J4.3, J4.4, J4.5, J5.2, J5.3, J5.4, J5.5, J6.2, J6.3, J6.4, J6.5, J7.2, J7.3, J7.4, J7.5, U5.2 (GND), U6.2 (GND), U7.2 (GND), U8.2 (GND); also elsewhere on the board
unnamed: J4.1, R29.2
unnamed: J5.1, R31.1
unnamed: J6.1, R33.2
unnamed: J7.1, R35.1
unnamed: R29.1, U5.4 (B)
unnamed: R28.2, U5.5 (DIR)
unnamed: R31.2, U6.4 (B)
unnamed: R30.2, U6.5 (DIR)
unnamed: R33.1, U7.4 (B)
unnamed: R32.2, U7.5 (DIR)
unnamed: R35.2, U8.4 (B)
unnamed: R34.2, U8.5 (DIR)


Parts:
C18, C19, C21, C22: 10u; C_0402_1005Metric_small_pads; LCSC C1856484
C20: 4.7u; C_0402_1005Metric_small_pads; LCSC C326586
J1: 61400416121
L2: 15u; IND_ASPI-4030S-150M-T; LCSC C5570254
L3: 22u; IND_ASPI6045S220MT; LCSC C187454
U1: NCP1117-3.3_SOT223; SOT-223-3_TabPin2; LCSC C26537
U3: NXE2S0505MC; Converter_DCDC_Murata_NXExSxxxxMC_SMD

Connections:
+3V3: C21.1, U1.2 (VO); also elsewhere on the board
+5V: C19.1, C22.1, L3.2, U1.3 (VI); also elsewhere on the board
/Power and Data/USB_D+: J1.3 (D+); also elsewhere on the board
/Power and Data/USB_D-: J1.2 (D-); also elsewhere on the board
GND: C19.2, C21.2, C22.2, U1.1 (GND), U3.7 (-VOUT); also elsewhere on the board
unnamed: L2.2, U3.3 (+VIN)
unnamed: L3.1, U3.8 (+VOUT)


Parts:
J13: 61611042121502
LED1: 5640100132F; Manufacturer_Part_Number 5640100132F
R8: 47k; R_0402_1005Metric; LCSC C176117
R9, R14, R15: 120; R_0402_1005Metric; LCSC C2100747

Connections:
+3V3: LED1.2 (A_GREEN), R8.1; also elsewhere on the board
/LEDs and Interlock/ERROR_LED: LED1.4 (A_YELLOW); also elsewhere on the board
/LEDs and Interlock/INTERLOCK_LED: LED1.6 (A_RED); also elsewhere on the board
/LEDs and Interlock/SAFETY_INTERLOCK: J13.1, R8.2; also elsewhere on the board
GND: J13.2, J13.3, J13.4, J13.5, R9.1, R14.2, R15.2; also elsewhere on the board
unnamed: LED1.1 (K_GREEN), R9.2
unnamed: LED1.5 (K_RED), R14.1
unnamed: LED1.3 (K_YELLOW), R15.1

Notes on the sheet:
Safety Interlock
Indicator Lights


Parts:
C23: 100n; C_0402_1005Metric_small_pads; LCSC C60474
J2: 61611042121502
R13: 470; R_0402_1005Metric; LCSC C482182
R27: 47k; R_0402_1005Metric; LCSC C176117
U4: SN74LVC1G17DCKR; SOT65P210X110-5N; DigiKey_Part_Number 296-11934-1-ND

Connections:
+3V3: C23.1, U4.5 (VCC); also elsewhere on the board
/Microcontroller and Ext. Clock/TRIGGER_1: U4.4 (Y); also elsewhere on the board
GND: C23.2, J2.2, J2.3, J2.4, J2.5, R27.2, U4.3 (GND); also elsewhere on the board
unnamed: J2.1, R13.1, R27.1
unnamed: R13.2, U4.2 (A)

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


Board: 4 copper layers, 100.0 x 100.0 mm, 86 parts (5 on the bottom side), 51 nets.

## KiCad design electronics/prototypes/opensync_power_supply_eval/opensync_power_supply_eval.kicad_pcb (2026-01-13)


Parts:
C1, C3, C4, C5: 10u; C_0402_1005Metric_small_pads; LCSC C1856484
C2: 4.7u; C_0402_1005Metric_small_pads; LCSC C326586
J1: 61400416121
L2: 15u; IND_ASPI-4030S-150M-T; LCSC C5570254
L3: 22u; IND_ASPI6045S220MT; LCSC C187454
TP1, TP2, TP3, TP4: TestPoint; TestPoint_Pad_2.0x2.0mm
U1: NCP1117-3.3_SOT223; SOT-223-3_TabPin2; LCSC C26537
U3: NXE2S0505MC; Converter_DCDC_Murata_NXExSxxxxMC_SMD

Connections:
+3V3: C4.1, TP1.1, U1.2 (VO)
+5V: C3.1, C5.1, L3.2, TP2.1, U1.3 (VI)
GND: C3.2, C4.2, C5.2, TP3.1, U1.1 (GND), U3.7 (-VOUT)
GND_BUS: C1.1, C2.1, J1.4 (GND), J1.S1, J1.S2, TP4.1, U3.1 (-VIN)
unnamed: L2.2, U3.3 (+VIN)
unnamed: L3.1, U3.8 (+VOUT)
VBUS: C1.2, C2.2, J1.1 (VBUS), L2.1


Board: 2 copper layers, 50.0 x 50.0 mm, 14 parts (0 on the bottom side), 7 nets.

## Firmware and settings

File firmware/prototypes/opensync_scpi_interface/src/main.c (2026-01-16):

#include <stdio.h>
#include <stdlib.h>

#include "pico/stdio.h"
#include "pico/stdlib.h"

#include "serial_interface/scpi-def.h"
#include "fast_serial.h"

#define SERIAL_BUFFER_SIZE 64

char serial_input_buffer[SERIAL_BUFFER_SIZE];

int main()
{
    stdio_init_all();

    // Initialize serial interface
	fast_serial_init();

    //Initialize SCPI interface
    scpi_instrument_init();

    while(1)
    {  
        uint32_t buf_len = fast_serial_read_until(
            serial_input_buffer, 
            SERIAL_BUFFER_SIZE, 
            '\n'
        );

        SCPI_Input(
            &scpi_context, 
            serial_input_buffer, 
            strlen(serial_input_buffer)
        );

    }

    return 0;
}

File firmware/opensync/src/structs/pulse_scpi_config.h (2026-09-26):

#pragma once

#include <stdbool.h>
#include <stdint.h>


#define MAX_CLOCK_SYNCS 1
#define MAX_PULSE_CHANNELS 8
#define MAX_PULSE_PAIR 6


enum {
    SCPI_GATE_DISABLED = 0,
    SCPI_GATE_PULSE = 1,
    SCPI_GATE_OUTPUT = 2,
    SCPI_GATE_CHANNEL = 3,
};

enum { 
    SCPI_GATE_LOW = 0, 
    SCPI_GATE_HIGH = 1 
};

enum { 
    SCPI_TRIGGER_DISABLED = 0, 
    SCPI_TRIGGER_ENABLED = 1 
};

enum {
    SCPI_TRIGGER_RISING = 0, 
    SCPI_TRIGGER_FALLING = 1 
};

struct pulse_scpi_config
{
    uint32_t clock_divider;
    bool state;
    uint32_t level;
    double period;                 // Seconds, after SCPI suffix conversion
    uint32_t bcounter;            // T0: acquisition quota
    uint32_t pcounter;
    uint32_t ocounter;
    uint32_t wcounter;
    uint32_t tcounter;
    uint32_t gate_mode;
    uint32_t gate_level;
    uint32_t trig_mode;
    uint32_t trig_edge;
    uint32_t sync;
    bool state_buffer[MAX_PULSE_PAIR];
    double delay_buffer[MAX_PULSE_PAIR];
};

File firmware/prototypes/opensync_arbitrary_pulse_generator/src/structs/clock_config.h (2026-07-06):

#pragma once 

#include <stdint.h>
#include "hardware/pio.h"

#define CLOCK_INSTRUCTIONS_MAX 16
// TODO: Rename this
#define CLOCK_TRIGGERS_MAX 2
#define CLOCKS_MAX 3
#define TRIGGERS_MAX 1

typedef enum {
    CLOCK_FREERUN = 0,
    CLOCK_TRIGGERED,
    CLOCK_TRIGGERED_RISING,
    CLOCK_TRIGGERED_HIGH,
    CLOCK_TRIGGERED_FALLING,
    CLOCK_TRIGGERED_LOW,
    CLOCK_TRIGGERED_SNIFFER
} clock_pio_program_t;

typedef enum {
    CLOCK_SCPI_MODE_FREERUN = 0,
    CLOCK_SCPI_MODE_SEQUENCER
} clock_scpi_mode_t;

typedef enum {
    CLOCK_TRIG_SOURCE_IMMEDIATE = 0,
    CLOCK_TRIG_SOURCE_EDGE,
    CLOCK_TRIG_SOURCE_GATE,
} clock_scpi_trigger_source_t;

typedef enum {
    CLOCK_TRIG_EDGE_POSITIVE = 0,
    CLOCK_TRIG_EDGE_NEGATIVE
} clock_scpi_trigger_edge_t;

typedef enum {
    CLOCK_GATE_LEVEL_HIGH = 0,
    CLOCK_GATE_LEVEL_LOW
} clock_scpi_gate_level_t;

typedef struct {
    clock_scpi_mode_t clock_mode;
    clock_scpi_trigger_source_t trigger_source;
    clock_scpi_trigger_edge_t edge;
    clock_scpi_gate_level_t gate_level;
} clock_scpi_config_t;

struct clock_config
{
    PIO pio;
    uint sm;
    uint program_offset;
    int dma_chan;
    uint32_t clock_pin;
    uint32_t trigger_pin;
    uint32_t clock_mode;
    uint32_t trigger_source;
    uint32_t trigger_edge;
    uint32_t trigger_level;
    uint32_t __attribute__((aligned(CLOCK_INSTRUCTIONS_MAX * sizeof(uint32_t)))) instructions[CLOCK_INSTRUCTIONS_MAX];
    uint32_t __attribute__((aligned(CLOCK_TRIGGERS_MAX     * sizeof(uint32_t)))) trigger_config[CLOCK_TRIGGERS_MAX];
    uint32_t trigger_reps;
    uint32_t clock_divider;
    double unit_offset;
    double unit_offset_trigger;
    bool active;
    bool configured;
};

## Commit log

2025-04-05 Update README.md
    - Switched to RP2350 microcontroller
2025-05-15 Update README.md
    - 24 Output channels pulled too much power to function properly.
    - Output channels were reduced to a maximum of 16 channels.
    - Added basic compilation information.
2025-05-18 Ambiguity in which pico sdk is being linked to
2025-05-28 I fixed it!!
    - Apparently, PIO blocks can spy on outputs passively. There is a 4 cycle jitter compared to 2 cycles for an external trigger, but hey, it works!!
    - This frees up 4 pins that can now go back to output channels (12 -> 16)
2025-05-29 Added stage 1 SDLC
2025-09-07 Initial assembly design
2025-09-10 Updated flowchart
2025-09-25 Fixed logic error (Tests passed)
    [core_1.c, sequencer_clock.c]
2025-09-28 Safety push: Computer making weird noises
    [clock_config.h, core_1.c, sequencer_clock.c]
2025-10-05 Initial KiCAD push
    [opensync.kicad_pcb, opensync.kicad_sch]
2025-10-17 Add upper-ish bound of PLL jitter
2025-10-17 Quick notebook on device
2025-10-17 Fixed clock divider debug
    [core_1.c]
2025-10-17 Flattened print statement
2025-10-24 Removed LED power button due to costs
2025-10-25 Fixed clock types issue
    [clock_config.h, core_1.c, sequencer_clock.c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]
2025-10-26 Fixed buffer alignment issue
    [clock_config.h, core_1.c]
2025-10-26 Fix clock buffer alignment
    [clock_config.h]
2025-10-31 Started on schematica again
    [microcontroller.kicad_sch, microcontroller_and_clock.kicad_sch, opensync.kicad_pcb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]
2025-11-01 Backup push
    [microcontroller.kicad_sch, microcontroller_and_clock.kicad_sch, opensync_prototype.kicad_sch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]
2025-11-01 Blank FreeCAD document
    [emclosure_protoype.FCStd]
2025-11-02 Ignore KiCAD backups
2025-11-05 KiCAD backup
    [input_ports.kicad_sch, microcontroller_and_clock.kicad_sch, opensync_prototype.kicad_sch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]
2025-11-10 Emergency backup
    [input_ports.kicad_sch, microcontroller_and_clock.kicad_sch, opensync_prototype.kicad_pcb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]
2025-11-11 Backup copy
    [microcontroller_and_clock.kicad_sch, opensync_prototype.kicad_pcb, output_ports.kicad_sch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]
2025-11-13 Updated jitter timing
2025-12-02 Updated PCB design
    [input_ports.kicad_sch, microcontroller_and_clock.kicad_sch, mount_holes.kicad_sch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]
2025-12-13 PCB rework
    [opensync_prototype.kicad_pcb]
2025-12-14 PCB trace routes
    [opensync_prototype.kicad_pcb]
2025-12-15 Hotel backup
    [opensync_prototype.kicad_pcb]
2025-12-15 Trace routing and vias
    [opensync_prototype.kicad_pcb]
2025-12-15 Routed buttons
    [opensync_prototype.kicad_pcb]
2025-12-15 Somewhat tighter trace matching
    [opensync_prototype.kicad_pcb]
2025-12-15 Updated board stackup
    [opensync_prototype.kicad_pcb]
2025-12-15 Impedance matching
    [opensync_prototype.kicad_pcb]
2025-12-16 Updated fills
    [opensync_prototype.kicad_pcb]
2025-12-16 Rearranged some stuff
    [opensync_prototype.kicad_pcb]
2025-12-16 Moved LED indicators
    [opensync_prototype.kicad_pcb]
2025-12-21 GFround and power plane rework
    [microcontroller_and_clock.kicad_sch, opensync_prototype.kicad_pcb, output_ports_1_to_4.kicad_sch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]
2025-12-21 Fixed RF jack problems and LED sketch
    [opensync_prototype.kicad_pcb]
2025-12-21 Increased spacing for output traces
    [opensync_prototype.kicad_pcb]
2025-12-21 Fixed all DRC violations
    [microcontroller_and_clock.kicad_sch, opensync_prototype.kicad_pcb]
2025-12-24 PCB touch-ups
    [microcontroller_and_clock.kicad_sch, opensync_prototype.kicad_pcb]
2025-12-24 Increased pwr/gnd trace width
    [opensync_prototype.kicad_pcb]
2025-12-24 Updated cooper pours
    [opensync_prototype.kicad_pcb]
2025-12-24 Fixed USB CAD render
    [opensync_prototype.kicad_pcb]
2025-12-24 PCB shenanigans
    [opensync_prototype.kicad_pcb]
2025-12-24 USB footprint edit
    [opensync_prototype.kicad_pcb]
2025-12-24 Gerber test
    [opensync_prototype-B_Cu.gbr, opensync_prototype-B_Mask.gbr, opensync_prototype-B_Paste.gbr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]
2025-12-28 Refined PCB
    [microcontroller_and_clock.kicad_sch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]
2025-12-29 Low cost 4ch prototype
    [input_ports.kicad_sch, microcontroller_and_clock.kicad_sch, mount_holes.kicad_sch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]
2025-12-29 Added gerber files
    [opensync_prototype-B_Cu.gbr, opensync_prototype-B_Mask.gbr, opensync_prototype-B_Paste.gbr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]
2025-12-29 PCB trace refinement
    [opensync_prototype-B_Cu.gbr, opensync_prototype-B_Mask.gbr, opensync_prototype-B_Paste.gbr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]
2025-12-30 4ch PCB fixup
    [opensync_prototype-B_Cu.gbr, opensync_prototype-B_Mask.gbr, opensync_prototype-B_Paste.gbr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]
2026-01-01 Included PCB design in SDLC
2026-01-05 Added part numbers
    [bom.csv, designators.csv, input_ports.kicad_sch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]
2026-01-05 Added more part numbers/updated PCB
    [bom.csv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]
2026-01-09 More prototyping
    [indicators_and_interlock.kicad_sch, input_ports.kicad_sch, microcontroller_and_clock.kicad_sch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]
2026-01-13 Finalized dev power PCB
    [bom.csv, designators.csv, opensync_power_supply_eval.kicad_pcb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]
2026-01-16 Hastily implemenmted scpi and finilaized PCB
2026-01-16 Added scpi-parser as submodule for prototype
2026-01-21 Fixed notes from drunk me
    [clock_config.h, sequencer_clock.c, sequencer_output.c]
2026-01-25 Finished on-device conversions
2026-01-25 Shoddy attempt to push w/o power and on solar panels
2026-01-26 Final push before battery dies
2026-01-28 Push after power back on and mornign worth of work
2026-06-07 Backup before storm
    [opensync_in_1.kicad_sch, opensync_interlock.kicad_sch, opensync_microcontroller.kicad_sch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]
2026-06-22 Backup after first PIV experiment
    [opensync_interlock.kicad_sch, opensync_mounting_holes.kicad_sch, opensync_status_indicators.kicad_sch]
2026-07-06 Emergency push before losing power
2026-07-06 Quick save before losing power from storm
    [prototype_eval.kicad_pcb]
2026-09-26 Ignore KiCad's .history files
2026-09-26 Uploaded PCB; remaining artifacts
    [agent-asc.kicad_pcb, agent-desc.kicad_pcb, agent-entry-vias.kicad_pcb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]
2026-09-27 Bug fixes; documentation generation
    [config_clock.rst.txt, config_pulse.rst.txt]
2026-09-28 General revisions
    [config_clock.rst.txt, config_pulse.rst.txt, opensync.kicad_pcb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]
2026-10-13 Updated new design; getting new PCBs

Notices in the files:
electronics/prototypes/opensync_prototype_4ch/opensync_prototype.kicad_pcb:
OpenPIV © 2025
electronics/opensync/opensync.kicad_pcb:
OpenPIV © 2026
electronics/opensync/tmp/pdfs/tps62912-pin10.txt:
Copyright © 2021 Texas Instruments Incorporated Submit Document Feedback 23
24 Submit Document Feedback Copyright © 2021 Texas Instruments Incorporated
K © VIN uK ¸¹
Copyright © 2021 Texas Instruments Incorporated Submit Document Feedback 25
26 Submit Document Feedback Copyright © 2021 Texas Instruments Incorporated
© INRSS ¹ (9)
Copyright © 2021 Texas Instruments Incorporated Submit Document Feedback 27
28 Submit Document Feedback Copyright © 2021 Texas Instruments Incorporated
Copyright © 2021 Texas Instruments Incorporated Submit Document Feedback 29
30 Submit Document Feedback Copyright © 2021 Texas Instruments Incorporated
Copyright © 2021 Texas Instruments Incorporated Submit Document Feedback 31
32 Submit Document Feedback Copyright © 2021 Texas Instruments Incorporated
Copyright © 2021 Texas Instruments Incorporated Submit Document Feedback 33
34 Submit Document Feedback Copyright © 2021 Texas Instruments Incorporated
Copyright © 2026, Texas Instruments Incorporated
